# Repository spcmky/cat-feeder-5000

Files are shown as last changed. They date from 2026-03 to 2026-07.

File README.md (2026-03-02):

# Cat Feeder 5000

An automated multi-cat feeder system with RFID-gated bowl access, camera-based cat identification, scheduled feeding, and remote web control. Built on Raspberry Pi + Arduino with fully 3D-printed enclosures.

## Project Overview

- **Units**: 2 identical feeders
- **Platform**: Raspberry Pi (main brain) + Arduino Nano (motor/servo/sensor control)
- **Access Control**: RFID collar tags + camera visual verification (dual-layer)
- **Features**: Scheduled feeding, portion control, remote web control, per-cat access gating
- **Fabrication**: All structural parts 3D-printed on LulzBot Taz / Pro
- **BOM**: ~$170/feeder

## Repository Structure

```
cat-feeder-5000/
├── docs/                        # Planning documents and specs
│   ├── master-plan.md           # Full project master plan
│   └── master-plan.docx         # Word version
├── hardware/
│   ├── bom/                     # Bill of materials (CSV + spreadsheet)
│   ├── wiring/                  # Wiring diagrams and pin maps
│   └── schematics/              # Circuit schematics
├── firmware/
│   └── cat-feeder-arduino/      # Arduino sketch
├── software/
│   ├── api/                     # Flask/FastAPI backend (Pi)
│   ├── camera/                  # Camera + cat ID module
│   ├── rfid/                    # RFID access control
│   └── web/                     # Web UI
├── 3d-models/
│   ├── stl/                     # Print-ready STL files
│   ├── cad/                     # Source CAD files
│   └── print-settings/          # LulzBot slicer profiles
└── assets/                      # Images, diagrams, visuals
```

## Quick Links

- [Master Plan](docs/master-plan.md)
- [Bill of Materials](hardware/bom/)
- [Wiring Diagrams](hardware/wiring/)
- [Arduino Firmware](firmware/cat-feeder-arduino/)
- [3D Print Files](3d-models/)

## Status

🟡 **Planning Phase** — master plan complete, fabrication and coding next.

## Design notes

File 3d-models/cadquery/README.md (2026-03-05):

# CadQuery Parts — STEP/STL Export

CadQuery (Python + OpenCascade) port of the OpenSCAD parts. **Design work
happens in OpenSCAD** (`../cad/`). This directory exists for two things:

1. **STEP + STL export** — machine shops, slicers, and CAD tools that don't
   read `.scad` files. Run `export_all.py` to batch-export everything.
2. **Geometry that OpenSCAD can't do well** — the auger screw uses a true
   parametric helix (`Wire.makeHelix` + `sweep`), and the antenna arch uses
   a swept elliptical profile along a 3-point arc. Both are approximations
   in OpenSCAD.

## Quick start

```bash
source .venv/bin/activate
python export_all.py                # → exports/ directory with STEP + STL
python export_all.py --outdir /tmp  # custom output path
python parts/p05_auger_screw.py     # build + export a single part
```

## Keeping in sync

If you change dimensions in `params.scad`, update `params.py` to match.
The CadQuery parts read from `params.py` only.

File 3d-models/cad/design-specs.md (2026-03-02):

# Cat Feeder 5000 — CAD Design Specifications
All dimensions in **millimeters**. Design in Fusion 360 or FreeCAD.
Coordinate system: X = width (left-right), Y = depth (front-back), Z = height (up-down).

---

## Overall Unit Envelope

| Dimension | Value | Notes |
|---|---|---|
| Width (X) | 160 mm | |
| Depth (Y) | 220 mm | Including bowl overhang |
| Height (Z) | 320 mm | Including hopper lid |
| Bowl approach clearance | ≥ 200 mm wide × 150 mm tall | Open front zone for cat access |

---

## Part 1 — Main Body / Base

**Function**: Structural core that all other parts mount into.

| Feature | Dimension |
|---|---|
| Outer width | 160 mm |
| Outer depth | 200 mm |
| Outer height | 200 mm |
| Wall thickness | 3 mm |
| Floor thickness | 4 mm |
| Front opening (bowl zone) | 120 mm wide × 100 mm tall |
| Electronics bay (rear lower) | 80 mm × 60 mm × 50 mm |
| Auger tube hole (center) | 40 mm dia pass-through |
| M3 heat-set insert bosses | Ø5.5 mm × 6 mm deep, ×12 locations |
| Rear cable pass-through | 15 mm dia, lower rear wall |
| Bottom feet pockets | 4× Ø10 mm × 3 mm deep, 10 mm from corners |

**Notes**: Front face has large opening for bowl approach. Electronics bay accessible from removable bottom cover. All internal corners at R2mm to reduce stress.

---

## Part 2 — Food Hopper

**Function**: Food reservoir. Sits on top of main body, funnels food into auger tube.

| Feature | Dimension |
|---|---|
| Top opening (square) | 130 mm × 130 mm |
| Bottom outlet (round) | Ø38 mm (matches auger tube OD) |
| Height | 130 mm |
| Wall thickness | 2.5 mm |
| Funnel angle | 50° from vertical (exceeds 45° min) |
| Capacity (approx) | ~500 mL / ~400 g dry kibble |
| Lip for lid | 3 mm ledge, 2 mm tall, around perimeter |
| Mount tabs | 4× M3 inserts on bottom flange |

**Notes**: No sharp interior corners at funnel transition — use R5mm fillet to prevent kibble bridging.

---

## Part 3 — Hopper Lid

**Function**: Snap/screw-on cover to keep food fresh and prevent pests.

| Feature | Dimension |
|---|---|
| Outer footprint | 136 mm × 136 mm |
| Height | 20 mm |
| Wall thickness | 2 mm |
| Inner lip (snap fit) | 2 mm wide × 3 mm tall, 0.4 mm interference fit |
| Filling port option | Optional 40 mm dia flip-door in center |

**Notes**: Add 4× small vent slots (1 mm × 10 mm) under lip to prevent vacuum seal. Center filling port is optional for top-up without full lid removal.

---

## Part 4 — Auger Tube

**Function**: Channel that auger screw rotates inside to move food from hopper to bowl drop point.

| Feature | Dimension |
|---|---|
| Inner diameter | 32 mm |
| Outer diameter | 38 mm |
| Length | 120 mm |
| Wall thickness | 3 mm |
| Angle from vertical | 30° (food flows toward front/bowl) |
| Top flange (hopper join) | Ø50 mm × 5 mm, M3 holes ×3 |
| Bottom exit port | Ø28 mm, angled 90° to tube axis |

**Notes**: Inner bore must be smooth — 0.15mm layer height, 3 perimeters, food-safe lubricant. Slight taper (0.5°) at bottom helps food exit cleanly.

---

## Part 5 — Auger Screw

**Function**: Rotates inside auger tube to move kibble. Motor-driven.

| Feature | Dimension |
|---|---|
| Outer diameter | 30 mm (1 mm clearance to tube ID) |
| Pitch (thread spacing) | 20 mm |
| Thread depth | 12 mm |
| Length | 115 mm |
| Motor shaft coupler bore | Ø5 mm (N20) or Ø5 mm flat (stepper) |
| Coupler length | 15 mm |

**Notes**: Print vertically for best thread layer adhesion. Each full rotation = ~8–12g kibble (calibrate `STEPS_PER_GRAM` in firmware after printing). Add M3 set screw hole through coupler section for shaft grip.

---

## Part 6 — Motor Mount

**Function**: Mounts the auger drive motor to the main body, aligned with auger tube.

| Feature | Dimension |
|---|---|
| Overall size | 60 mm × 50 mm × 30 mm |
| Motor pocket (N20) | 12 mm × 10 mm × 25 mm deep |
| Motor pocket (stepper) | 28 mm sq × 20 mm deep |
| Shaft center offset | Matches auger tube center axis |
| Mount holes | 4× M3, matches main body bosses |

**Notes**: Design for either N20 or NEMA14 stepper (separate variants or universal with insert). Motor pocket should have 0.2 mm clearance on all sides.

---

## Part 7 — Electronics Tray

**Function**: Snap-in tray holding Pi, Arduino Nano, wiring, and power components.

| Feature | Dimension |
|---|---|
| Outer size | 78 mm × 58 mm × 20 mm |
| Pi Zero 2 W pocket | 65 mm × 30 mm × 6 mm deep |
| Arduino Nano pocket | 45 mm × 18 mm × 8 mm deep |
| Wire channel width | 8 mm |
| Snap clips | 2× 2 mm wide × 4 mm tall, 0.5 mm interference |
| Standoff height (Pi) | 3 mm (M2.5 or snap-peg style) |

**Notes**: Include cable tie slots (3 mm × 1.5 mm) every 30 mm along perimeter. Tray slides into main body from rear. Ventilation holes (Ø3 mm, 6× min) above Pi.

---

## Part 8 — Electronics Cover

**Function**: Covers electronics bay. Ventilated, removable.

| Feature | Dimension |
|---|---|
| Outer size | 84 mm × 64 mm × 5 mm |
| Vent slots | 20× slotted 2 mm × 15 mm, 3 mm spacing |
| Retention clip | 1× snap clip center, or 2× M3 screws |

---

## Part 9 — Bowl (Open-Front Design)

**Function**: Food bowl. Whisker-friendly open-front design.

| Feature | Dimension |
|---|---|
| Internal floor width | 100 mm |
| Internal floor depth | 90 mm (front-to-back) |
| Side wall height | 25 mm |
| Back wall height | 30 mm |
| Front wall | **NONE** — fully open face |
| Floor thickness | 3 mm |
| Side wall thickness | 2.5 mm |
| Floor front overhang past opening | 15 mm |
| Mounting tabs (rear) | 2× M3 insert, 10 mm from sides |
| Corner radius (internal) | R10 mm — easy cleaning |
| Drain holes (optional) | 4× Ø3 mm in floor corners |

**Notes**: The open front means no wall on the cat-facing side. Side walls taper from 25 mm at front to 30 mm at back to loosely guide food. Floor extends 15 mm past the gate opening plane so food doesn't fall out when gate opens. All interior surfaces smooth (0.15 mm layer height).

---

## Part 10 — Bowl Mounting Bracket

**Function**: Attaches bowl to main body front opening at correct height.

| Feature | Dimension |
|---|---|
| Overall size | 110 mm × 30 mm × 20 mm |
| Bowl attachment | 2× M3 holes, 90 mm apart |
| Body attachment | 4× M3 holes, countersunk |
| Bowl height from floor | Sets bowl floor at 40 mm above base |
| Tilt angle | 2° downward-front (prevents food sliding back) |

---

## Part 11 — Camera Mount / Arm

**Function**: Positions Pi Camera above and behind the bowl opening for top-down cat face view.

| Feature | Dimension |
|---|---|
| Arm length | 80 mm |
| Camera face angle | 45° downward from horizontal |
| Camera pocket | 25 mm × 25 mm × 5 mm, M2 mounts × 4 |
| Body attachment (swivel base) | M3 × 2, 15 mm apart |
| Horizontal swivel range | ±20° (slot + clamp bolt) |

**Notes**: Print with supports under the angled camera head. Camera should face down-forward to capture cat's face from ~150–200 mm distance as cat eats.

---

## Part 12 — Camera Cover / Bezel

**Function**: Cosmetic trim ring around camera lens. Protects from food dust.

| Feature | Dimension |
|---|---|
| Lens opening | Ø10 mm (Pi Camera lens is ~7.5 mm dia) |
| Outer footprint | 30 mm × 30 mm |
| Depth | 8 mm |
| Snap clips | 4× small 1 mm clips to camera mount |

---

## Part 13 — Bowl Gate / Flap (Swing-Up)

**Function**: Blocks bowl opening when closed. Swings up into feeder body when open. Servo-actuated.

| Feature | Dimension |
|---|---|
| Flap width | 118 mm (2 mm clearance each side in 120 mm opening) |
| Flap height | 90 mm (covers full bowl approach opening) |
| Thickness | 3 mm |
| Hinge rod holes (top edge) | 2× Ø3.2 mm, 20 mm from each end |
| Servo linkage hole (top center) | Ø3 mm, 10 mm from top edge |
| Bottom edge profile | R5 mm radius — no sharp edge facing cat |
| Closed position overlap | 5 mm overlap with bowl bracket each side |

**Notes**: When open (servo pulls top rearward and up), flap pivots 95–100° and rests against internal stop inside feeder body. Cat's head position during eating is ~80 mm below the hinge line — no contact possible. Print flat (face down). No texture on cat-facing side.

---

## Part 14 — Gate Top Hinge Mount

**Function**: Holds the gate flap hinge rod. Fixed to top of bowl opening frame.

| Feature | Dimension |
|---|---|
| Width | 120 mm (spans full opening) |
| Height | 20 mm |
| Depth | 15 mm |
| Hinge rod bore | 2× Ø3.2 mm, press-fit M3 shaft or use Ø3mm rod |
| Rod center height from top | 8 mm |
| Body attachment holes | 4× M3, evenly spaced |

**Notes**: Rod sits just inside the feeder body plane so gate can swing inward (upward) cleanly.

---

## Part 15 — Antenna Arch Housing

**Function**: Overhead arch that cradles the flat RFID antenna coil above the bowl approach zone.

| Feature | Dimension |
|---|---|
| Arch inner span (X) | 160 mm (full feeder width) |
| Arch inner height (Z above bowl rim) | 70 mm at peak |
| Arch depth (Y, front-to-back) | 40 mm |
| Coil channel width | 16 mm |
| Coil channel depth | 5 mm (recessed, no top perimeters over channel) |
| Coil center height above bowl floor | ~90–110 mm (adjust: want 50–80 mm above cat shoulder level) |
| Wall thickness | 2.5 mm |
| Body mount tabs | 2× M3 each side, into main body top |
| Coil channel position | Centered horizontally, centered front-to-back in arch |

**Notes**: Arch must not restrict the cat's head/neck access to the bowl. Profile: semi-elliptical arch, widest at base. Internal coil channel is open-top (no perimeter bridging over it) — coil wire is seated and fixed with food-safe epoxy. Route antenna cable through a 5 mm dia channel in the arch wall to the electronics bay.

---

## Part 16 — Gate Servo Bracket

**Function**: Mounts SG90 servo inside feeder body, connects via linkage arm to gate flap top.

| Feature | Dimension |
|---|---|
| Servo pocket | 23 mm × 12.5 mm × 30 mm deep (SG90 body) |
| Servo ear mounting holes | M2 × 2, 28 mm apart (SG90 spec) |
| Body attachment | M3 × 2 |
| Linkage arm pivot hole | Ø2 mm, 15 mm from servo shaft center |
| Position in body | Above gate hinge, ~20 mm from top wall |

**Notes**: Orient servo so horn rotates in vertical plane parallel to gate travel. With horn at 0° gate is closed; at ~95° gate is fully open (flap resting on bumper).

---

## Part 17 — TPU Gate Bumper

**Function**: Soft end-stop for gate flap in fully-open position. Absorbs servo overrun.

| Feature | Dimension |
|---|---|
| Overall size | 30 mm × 15 mm × 8 mm |
| Shore hardness | TPU 95A preferred |
| Mounting | Press-fit or M2 screw into feeder body rear wall |
| Contact face | Full 30 mm × 8 mm surface (spread impact) |
| Position | Where gate flap top edge rests when fully open |

---

## Part 18 — Feet / Non-Slip Pads

**Function**: Press-fit rubber feet, one at each corner of base. Prevents sliding.

| Feature | Dimension |
|---|---|
| Body (press-fit stud) | Ø9.8 mm dia × 6 mm tall (0.2 mm interference with Ø10 mm pocket) |
| Pad base | Ø16 mm × 4 mm |
| Material | TPU 95A |
| Quantity | 4 per unit |

---

## General Design Notes

- All M3 heat-set insert bores: **Ø4.7 mm** (M3 insert OD = 4.5 mm, +0.2 mm for print tolerance)
- All M3 clearance holes (screws pass through): **Ø3.4 mm**
- All M3 captive/tapped holes: **Ø2.5 mm** (tap M3 after printing, or use insert)
- Standard print tolerance: **±0.2 mm** — design snap fits with 0.3–0.5 mm interference
- PETG shrinkage: **~0.3–0.5%** — negligible at these scales, no compensation needed for LulzBot
- All food-contact surfaces: smooth finish (0.15 mm layer height), no sharp interior corners < R3 mm

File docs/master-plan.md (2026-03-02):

# Cat Feeder 5000 — Master Plan
**Project**: Automated Multi-Cat Feeder System
**Units**: 2 identical feeders
**Date**: 2026-03-02
**Version**: 1.2 (implanted microchip RFID + swing-up gate)

---

## Table of Contents

1. [Project Overview](#1-project-overview)
2. [System Architecture](#2-system-architecture)
3. [Bill of Materials](#3-bill-of-materials)
4. [3D-Printed Parts](#4-3d-printed-parts)
5. [Wiring & Electronics](#5-wiring--electronics)
6. [Arduino Firmware](#6-arduino-firmware)
7. [Raspberry Pi Software](#7-raspberry-pi-software)
8. [Web Interface & API](#8-web-interface--api)
9. [Design Rationale](#9-design-rationale)
10. [Risk Mitigation](#10-risk-mitigation)
11. [Project Phases & Deliverables](#11-project-phases--deliverables)

---

## 1. Project Overview

### Goal
Build two identical automated cat feeders that:
- Dispense precise food portions on a schedule
- Enforce per-cat access by reading the cat's **implanted microchip** (no collar required)
- Use a camera to visually verify which cat is present (cross-check)
- Allow full remote monitoring and control via a web app
- Are housed in professional-looking, fully 3D-printed enclosures

### Key Design Decisions
- **Open-front bowl**: Bowl has no walls at the cat's face side — low 25mm side walls, forward-extending floor. Whisker-friendly, comfortable eating position.
- **Implanted chip RFID**: Uses each cat's existing ISO 11784/11785 FDX-B microchip (134.2 kHz, implanted between the shoulders). No collar or tag required. Reader uses an EM4095 analog front end with a custom flat coil antenna mounted overhead.
- **Overhead antenna arch**: The antenna coil is positioned in a horizontal arch above and just behind the bowl opening, so the chip passes directly under it as the cat lowers its head to eat. The antenna never contacts the cat.
- **Swing-up gate**: The bowl gate flap is hinged at the top and swings up into the feeder body when open. The cat's head and back are never in the path of the gate — it cannot hit them.
- **Dual-layer cat ID**: RFID handles physical enforcement (gate open/close); camera handles visual verification and smart alerts. Cross-verification catches edge cases.
- **Two-board design**: Pi handles compute-heavy tasks (camera, web server, RFID logic). Arduino handles real-time 5V peripherals (motors, servos, sensors).

---

## 2. System Architecture

### Hardware Architecture

```
┌─────────────────────────────────────────────────────┐
│              Raspberry Pi (per feeder)               │
│  - Web server (Flask/FastAPI)                        │
│  - Camera + cat ID (OpenCV)                          │
│  - RFID access logic                                 │
│  - Schedule manager                                  │
│  - Database (SQLite)                                 │
│  - Serial comms to Arduino                           │
└──────────────────────┬──────────────────────────────┘
                       │ USB Serial (115200 baud)
┌──────────────────────▼──────────────────────────────┐
│              Arduino Nano (per feeder)               │
│  - Auger/dispense motor (stepper or DC)              │
│  - Bowl gate servo (SG90, pin D8)                    │
│  - EM4095 RFID AFE (SPI, pins D10-D13) + coil antenna│
│  - Buzzer (pin A2)                                   │
│  - Weight/load sensor (optional)                     │
│  - Status LED                                        │
└──────────────────────────────────────────────────────┘
```

### Network Architecture

```
[Cat Feeder Unit 1] ──┐
                       ├── Local WiFi ── [Router] ── [Internet]
[Cat Feeder Unit 2] ──┘                     │
                                            │
                                    [Web App / Mobile]
                                    (remote monitoring)
```

### Serial Protocol (Pi ↔ Arduino)

| Direction | Command | Description |
|---|---|---|
| Pi → Arduino | `FEED:<grams>` | Dispense specified portion |
| Pi → Arduino | `GATE:OPEN` | Open bowl gate |
| Pi → Arduino | `GATE:CLOSE` | Close bowl gate |
| Arduino → Pi | `EVENT:RFID:<uid>` | RFID tag detected (UID string) |
| Arduino → Pi | `EVENT:WEIGHT:<grams>` | Current bowl weight |
| Arduino → Pi | `STATUS:READY` | Arduino boot complete |

---

## 3. Bill of Materials

**Estimated cost: ~$170 per feeder** (×2 = ~$340 total)

### Core Electronics

| Qty | Component | Est. Cost | Notes |
|-----|---|---|---|
| 1 | Raspberry Pi Zero 2 W | $15 | Or Pi 4 for more headroom |
| 1 | Arduino Nano | $5 | Clone acceptable |
| 1 | EM4095 RFID analog front end (AFE) | $3 | 125 kHz AFE, tune LC tank to 134.2 kHz for FDX-B; SPI; 5V native — no level shifter needed. Alt: TMS3705 (TI, dedicated 134.2 kHz animal ID IC, harder to source) |
| 1 | Antenna coil (custom wound or pre-made) | $3 | Flat spiral coil, ~10–15cm diameter, tuned to 134.2 kHz with capacitor. Mounted overhead in arch housing above cat's shoulders |
| 1 | Tuning capacitor for antenna | $1 | LC tank cap, value calculated for 134.2 kHz resonance with chosen coil |
| 1 | Pi Camera Module 3 (or V2) | $25 | Wide angle preferred |
| 1 | SG90 micro servo (gate) | $3 | Swing-up gate actuation |
| 1 | N20 gear motor or NEMA 14 stepper | $8 | Auger drive |
| 1 | Motor driver (L298N or A4988) | $3 | |
| 1 | Active buzzer 5V | $1 | Feeding alert |
| 1 | 5V 3A power supply (USB-C) | $10 | Powers Pi + Arduino |
| 1 | Micro SD card 32GB | $8 | Pi OS + data |

### Mechanical & Hardware

| Qty | Component | Est. Cost | Notes |
|-----|---|---|---|
| 1 | Food-grade PETG filament (1kg) | $25 | Main body, hopper, bowl |
| 1 | TPU filament (200g) | $8 | Gate bumper, feet |
| 1 | M3 heat-set inserts (50 pack) | $6 | Assembly fasteners |
| 1 | M3 screws assorted (100 pack) | $5 | |
| 1 | Silicone food bowl liner (optional) | $5 | Hygiene, replaceable |
| — | Misc: wire, connectors, JST | $10 | |

**Total per feeder: ~$140–170 depending on sourcing**

---

## 4. 3D-Printed Parts

All parts printed on LulzBot Taz or Pro. Primary material: PETG (food-safe, durable). Gate bumper: TPU (flexible, quiet).

### Complete Parts List (18 parts)

| # | Part Name | Material | Layer Height | Infill | Supports | Notes |
|---|---|---|---|---|---|---|
| 1 | Main body / base | PETG | 0.25mm | 40% | No | Structural core, fits all internals |
| 2 | Food hopper | PETG | 0.25mm | 25% | No | 1–2 cup capacity, funnel angle ≥45° |
| 3 | Hopper lid | PETG | 0.2mm | 20% | No | Snap or screw-on, keeps food fresh |
| 4 | Auger tube | PETG | 0.2mm | 30% | No | Food-grade, smooth inner bore |
| 5 | Auger screw | PETG | 0.15mm | 60% | Yes | Precision thread, calibrate for portion accuracy |
| 6 | Motor mount | PETG | 0.25mm | 40% | No | Mounts auger drive motor |
| 7 | Electronics tray | PETG | 0.25mm | 30% | No | Holds Pi, Arduino, wiring; snap-in |
| 8 | Electronics cover | PETG | 0.2mm | 20% | No | Ventilation slots, removable |
| 9 | Bowl — open-front design | PETG | 0.15mm | 30% | No | No face-side wall; low 25mm side walls; floor extends forward; whisker-friendly |
| 10 | Bowl mounting bracket | PETG | 0.25mm | 40% | No | Secures bowl to main body |
| 11 | Camera mount / arm | PETG | 0.2mm | 35% | Yes | Angled for top-down cat face view |
| 12 | Camera cover / bezel | PETG | 0.2mm | 20% | No | Cosmetic, protects lens |
| 13 | **Bowl gate / flap — swing-up** *(RFID)* | PETG | 0.15mm | 40% | No | Hinged at top of bowl opening; swings up into feeder body when open. Cat's head and back are never in the path of travel. Servo-actuated |
| 14 | **Gate top hinge mount** *(RFID)* | PETG | 0.2mm | 40% | No | Mounts gate flap pivot at top of bowl opening; keeps gate travel path above the cat |
| 15 | **Antenna arch housing** *(RFID)* | PETG | 0.2mm | 25% | No | Overhead arch that positions the flat coil antenna horizontally above the approach zone, ~5–8cm above where the cat's shoulders sit while eating. Coil slots into a recessed channel inside the arch. Sized so gate flap retracts into the feeder body above it |
| 16 | **Gate servo bracket** *(RFID)* | PETG | 0.2mm | 40% | No | Mounts SG90 servo inside feeder body; linkage arm connects to top of gate flap |
| 17 | **TPU gate bumper** *(RFID)* | TPU | 0.2mm | 30% | No | Soft stop at top of gate travel (fully open position); prevents servo overrun and rattle |
| 18 | Feet / non-slip pads | TPU | 0.3mm | 15% | No | 4 per unit, press-fit into base |

### LulzBot Print Notes

- **PETG settings (Taz/Pro)**: 240°C nozzle / 70–80°C bed. 0.5mm nozzle recommended for structural parts. Dry filament before printing (PETG is hygroscopic).
- **TPU settings**: 220°C nozzle / 45°C bed. Disable retraction or minimize. Print slow (25–30mm/s).
- **Food contact parts** (auger, bowl): Use food-safe PETG, 3+ perimeters, 40%+ infill, food-safe lubricant only on auger.
- **Orientation**: Print auger screw vertically for thread integrity. Print gate flap flat (face down). Print antenna arch upright — thin walls need orientation parallel to print direction for layer bonding strength.
- **Antenna coil channel**: Leave a 2–3mm recessed groove inside the arch for the coil wire. Print without top-surface perimeters over the channel so coil can be seated and epoxied in place.

---

## 5. Wiring & Electronics

### Arduino Pin Map

| Pin | Function | Component |
|-----|---|---|
| D2 | Stepper STEP or motor PWM | Motor driver |
| D3 | Stepper DIR or motor IN2 | Motor driver |
| D4 | Motor driver enable | L298N/A4988 EN |
| D5 | RFID modulation (MOD) | EM4095 |
| D6 | RFID RF off (RF_OFF) | EM4095 |
| D8 | Gate servo PWM | SG90 servo (swing-up gate) |
| D9 | Status LED | LED + resistor |
| **D10** | **RFID chip select (CS)** | **EM4095** |
| **D11** | **SPI MOSI** | **EM4095** |
| **D12** | **SPI MISO / DEMOD_OUT** | **EM4095** |
| **D13** | **SPI SCK** | **EM4095** |
| A2 | Buzzer | Active buzzer |
| A4 | I2C SDA (optional) | Load cell amp |
| A5 | I2C SCL (optional) | Load cell amp |

> **NOTE**: EM4095 is a **5V device** — no level converter needed. Power directly from Arduino 5V. The antenna coil connects to the COIL1/COIL2 pins on the EM4095 via the LC tank circuit (coil + tuning cap resonant at 134.2 kHz).

### Antenna Coil Design

The read range and reliability of the implanted chip detection depends entirely on the antenna coil. Key parameters:

| Parameter | Target value |
|---|---|
| Coil diameter | 10–15 cm flat spiral |
| Number of turns | 10–20 (tune for resonance) |
| Resonant frequency | 134.2 kHz (FDX-B) |
| Target read range | 5–8 cm (sufficient for chip ~2–4 cm below skin) |
| Coil position | Horizontal, centered in arch housing, ~5–8 cm above cat shoulder level |
| Coil orientation | Flat/horizontal — maximizes flux through chip (chip axis is vertical when cat's back is level) |

**LC tank resonance formula**: `f = 1 / (2π√(LC))` — choose L (coil inductance), solve for C. Wind coil, measure inductance with LCR meter or Arduino LC meter, then calculate exact cap value.

### Power Architecture

```
USB-C 5V 3A PSU
    ├── Raspberry Pi (5V via USB-C)
    └── Arduino Nano (5V via USB or Vin)
            ├── SG90 servo (5V, ~250mA peak)
            ├── Motor driver (5V logic, motor on separate 5-12V if needed)
            ├── Buzzer (5V)
            └── EM4095 + coil antenna (5V, ~50–100mA during read)
```

### RFID Wiring (EM4095 ↔ Arduino Nano)

| EM4095 Pin | Arduino Pin | Notes |
|---|---|---|
| VCC | 5V | 5V native — no level shifter |
| GND | GND | |
| COIL1 | — | To LC tank coil (one end) |
| COIL2 | — | To LC tank coil (other end) |
| DEMOD_OUT | D12 (MISO) | Demodulated data out |
| MOD | D5 | Modulation input (for write capability) |
| RF_OFF | D6 | Pull high to disable RF field |
| SHD | GND | Pull low to enable (or use D-pin for software control) |

---

## 6. Arduino Firmware

### Responsibilities
- Drive the EM4095 antenna coil to read FDX-B implanted microchip UIDs; report to Pi over serial
- Actuate swing-up gate servo (open = flap retracts into body above bowl; close = flap blocks bowl opening)
- Drive auger motor for food dispensing (on Pi command)
- Sound buzzer for feeding alerts
- Optionally read load cell for bowl weight

### Key Serial Commands

```
Pi → Arduino:
  FEED:<grams>        — dispense specified grams
  GATE:OPEN           — open bowl gate flap
  GATE:CLOSE          — close bowl gate flap
  BUZZ:<pattern>      — trigger buzzer (1=short, 2=long, 3=error)

Arduino → Pi:
  EVENT:RFID:<uid>    — RFID tag detected with UID
  EVENT:WEIGHT:<g>    — bowl weight reading
  STATUS:READY        — boot complete
  STATUS:GATE:OPEN    — gate opened confirmation
  STATUS:GATE:CLOSED  — gate closed confirmation
```

### Gate State Machine

```
[CLOSED] → RFID detected → Pi validates → GATE:OPEN → [OPEN]
[OPEN] → 30s timeout → GATE:CLOSE → [CLOSED]
[OPEN] → cat leaves (weight sensor) → GATE:CLOSE → [CLOSED]
```

### Source Files
- `firmware/cat-feeder-arduino/cat-feeder-arduino.ino` — main sketch
- Libraries: `Servo`, `AccelStepper`
- RFID decoding: custom Manchester decoder for FDX-B bit stream from EM4095 DEMOD_OUT. No off-the-shelf Arduino library covers EM4095 + FDX-B directly — implementation uses timer interrupt to sample DEMOD_OUT at 2× bit rate and decode Manchester encoding.

---

## 7. Raspberry Pi Software

### Python Modules

| Module | File | Purpose |
|---|---|---|
| Main daemon | `main.py` | Orchestrates all services |
| Schedule manager | `scheduler.py` | Feeding schedule, cron-like |
| Serial bridge | `serial_bridge.py` | Pi ↔ Arduino serial comms |
| RFID access control | `rfid_access.py` | Tag registration, access decisions |
| Gate controller | `gate_controller.py` | Gate open/close logic, timeout |
| Camera / cat ID | `camera.py` | OpenCV, cat face detection |
| Database | `db.py` | SQLite ORM layer |
| API server | `api/app.py` | Flask/FastAPI REST API |

### Database Schema (SQLite)

```sql
-- Cats
CREATE TABLE cats (
  id INTEGER PRIMARY KEY,
  name TEXT NOT NULL,
  rfid_uid TEXT,           -- RFID collar tag UID
  photo_embedding BLOB,    -- Camera ID feature vector
  daily_portion_g INTEGER DEFAULT 80,
  created_at TIMESTAMP DEFAULT CURRENT_TIMESTAMP
);

-- RFID tags
CREATE TABLE rfid_tags (
  id INTEGER PRIMARY KEY,
  uid TEXT UNIQUE NOT NULL,
  cat_id INTEGER REFERENCES cats(id),
  active BOOLEAN DEFAULT 1,
  registered_at TIMESTAMP DEFAULT CURRENT_TIMESTAMP
);

-- Feeding events
CREATE TABLE feeding_log (
  id INTEGER PRIMARY KEY,
  cat_id INTEGER REFERENCES cats(id),
  feeder_id INTEGER,
  trigger TEXT,            -- 'schedule', 'manual', 'rfid'
  portion_g INTEGER,
  dispensed_at TIMESTAMP DEFAULT CURRENT_TIMESTAMP
);

-- RFID access events
CREATE TABLE access_log (
  id INTEGER PRIMARY KEY,
  rfid_uid TEXT,
  cat_id INTEGER REFERENCES cats(id),
  feeder_id INTEGER,
  result TEXT,             -- 'granted', 'denied', 'unknown_tag'
  camera_verify TEXT,      -- 'match', 'mismatch', 'skipped'
  accessed_at TIMESTAMP DEFAULT CURRENT_TIMESTAMP
);

-- Feeding schedules
CREATE TABLE schedules (
  id INTEGER PRIMARY KEY,
  feeder_id INTEGER,
  cat_id INTEGER REFERENCES cats(id),
  time TEXT NOT NULL,      -- 'HH:MM' format
  portion_g INTEGER,
  enabled BOOLEAN DEFAULT 1
);
```

### Cat Identification Pipeline

```
1. RFID tag detected (Arduino → Pi)
2. Pi looks up tag in rfid_tags table → gets cat_id
3. Pi sends GATE:OPEN to Arduino (physical access granted)
4. Camera captures frame, runs face detection (OpenCV)
5. Compare detected cat against registered cat embeddings
6. If RFID cat ≠ camera cat → log alert, optionally close gate
7. Log event to access_log with both RFID and camera results
```

---

## 8. Web Interface & API

### REST API Endpoints

| Method | Endpoint | Description |
|---|---|---|
| GET | `/api/status` | Feeder status, last event |
| GET | `/api/cats` | List registered cats |
| POST | `/api/cats` | Register new cat |
| GET | `/api/feeding-log` | Recent feeding history |
| POST | `/api/feed` | Manual feed trigger |
| GET | `/api/schedule` | Get feeding schedule |
| PUT | `/api/schedule` | Update schedule |
| GET | `/api/rfid/tags` | List registered RFID tags |
| POST | `/api/rfid/pair` | Pair new RFID tag to cat |
| DELETE | `/api/rfid/tags/:id` | Remove RFID tag |
| POST | `/api/gate/open` | Manual gate open |
| POST | `/api/gate/close` | Manual gate close |
| GET | `/api/access-log` | RFID access event log |
| GET | `/api/camera/snapshot` | Live camera frame |

### Web UI Features
- Dashboard: live status for both feeders
- Feeding history chart (per cat, per day)
- Schedule editor (drag-and-drop time slots)
- Cat profile management (photo, name, portion size)
- RFID tag management (pair, disable, re-pair)
- Access log with camera snapshots
- Manual feed button
- Gate control (override open/close)

---

## 9. Design Rationale

### Why Pi + Arduino (not Pi alone)?
The Pi GPIO is not well-suited for real-time PWM servo/stepper control, and 5V peripherals require level shifting. The Arduino handles time-critical 5V tasks reliably, while the Pi focuses on compute: camera inference, web serving, and RFID logic. USB serial provides a clean, reliable bridge.

### Why Implanted Chip (Not Collar Tag)?
The cat's ISO 11784/11785 FDX-B microchip is already implanted between the shoulders — it's permanent, can't be removed, lost, or swapped between cats. Collar tags require the cat to always be wearing the collar, and cats are notorious for losing them. Using the implanted chip eliminates an entire class of failure modes and means no new hardware needs to be attached to the cat.

### Why EM4095 + Custom Coil (Not RC522/MFRC522)?
The MFRC522 operates at 13.56 MHz (ISO 14443 / ISO 15693) — it physically cannot read implanted pet microchips, which operate at 134.2 kHz (FDX-B). The EM4095 is a 5V-native LF analog front end designed for exactly this frequency range. A custom-wound flat coil tuned to 134.2 kHz via an LC tank gives precise control over read range and antenna geometry.

### Why Overhead Antenna Arch (Not Front-Mounted)?
The microchip is between the cat's shoulder blades. As the cat lowers its head to the bowl, the shoulders are roughly level with the bowl rim. A front-mounted antenna would require the chip to pass horizontally through the read field — awkward geometry, poor coupling. An overhead flat coil positioned above the shoulder zone reads the chip at nearly optimal angle (coil plane parallel to the cat's back, flux perpendicular to chip axis) as the cat settles into eating position.

### Why RFID + Camera (dual-layer)?
RFID alone can't catch the edge case of one cat crouching right behind another. Camera alone is compute-heavy and can fail in low light. Together they provide reliable access: RFID opens the gate physically, camera confirms visually and catches anomalies.

### Why Open-Front Bowl?
Cats have sensitive whiskers. Deep or walled bowls cause "whisker fatigue" — discomfort when whiskers touch bowl sides during eating. The open-front design with low 25mm side walls and a forward-extending floor allows cats to eat comfortably without whisker contact, while still containing food adequately.

### Why RFID Gate Instead of Camera-Gated Gate?
Camera inference adds latency (100–500ms) on a Pi Zero. An RFID reader responds in <50ms and requires no compute. Using RFID for the physical gate and camera only for cross-verification gives fast, reliable physical access control with the smart verification layer as a safety net.

### Why Swing-Up Gate?
A downward-swinging or forward-opening gate creates a collision risk as the cat approaches or backs away. A swing-up gate retracts fully into the feeder body above the bowl — it is physically impossible for it to contact the cat's head or back during normal operation. The servo travel path is internal to the unit.

### Why Full 3D-Print?
Full 3D printing means every dimension can be tuned, iterated, and upgraded without new tooling. PETG is food-safe, durable, and easy to clean. Custom prints also enable purpose-fit cable routing, snap-fit assembly, and aesthetics not possible with off-the-shelf parts.

---

## 10. Risk Mitigation

| Risk | Likelihood | Impact | Mitigation |
|---|---|---|---|
| Wrong cat eats from open feeder | Medium | High | RFID gate physically blocks access; camera cross-checks |
| Chip not read as cat approaches | Low | Medium | Antenna coil sized and positioned for optimal coupling; cat must be in position to eat before gate opens anyway; retry logic in firmware polls at ~10 Hz |
| Chip read angle poor (cat tilts/crouches oddly) | Low | Low | Flat coil with 10–15cm diameter gives generous field volume; minor angle variation (<30°) has negligible effect on FDX-B coupling |
| Gate hits cat | Very Low | Medium | Swing-up design: gate retracts into body above the bowl — physically cannot contact the cat. TPU bumper stops servo at top of travel |
| Gate servo jam | Low | Medium | 30s auto-close timeout; manual override in web UI; swing-up means gravity assists closing |
| Two cats approach simultaneously | Low | Medium | Gate only opens for one UID at a time; coil read range limited to ~8cm so second cat is too far to trigger |
| Antenna LC tank drifts off resonance (temperature) | Low | Low | PETG housing insulates coil; resonance measured at room temp; minor drift at 134.2 kHz is tolerable given FDX-B chip sensitivity |
| Pi Zero underpowered for camera + web | Medium | Low | Optimize OpenCV pipeline; or upgrade to Pi 4 Model B |
| Auger clog | Medium | Medium | Food-grade PETG smooth bore; minimum 45° hopper angle; jam-detection via stall sensing |
| Food spoilage in hopper | Low | Medium | Hopper lid keeps food fresh; programmable max daily portion limits |
| Cat ignores feeder | Low | Low | Schedule-based buzz alert; treat-dispensing mode as incentive |

---

## 11. Project Phases & Deliverables

### Phase 1 — Hardware & Prototyping (Weeks 1–3)
- [ ] Source all components (BOM)
- [ ] Wind test coil, calculate LC tank cap for 134.2 kHz, verify resonance with LCR meter
- [ ] Breadboard test: Arduino + EM4095 + test coil → successfully read cat's implanted chip
- [ ] Verify read range with coil at different heights above cat's shoulders
- [ ] Breadboard test: swing-up gate servo travel and clearance geometry
- [ ] Validate serial protocol between Pi and Arduino
- [ ] Test camera with basic OpenCV cat detection

### Phase 2 — 3D Design & Printing (Weeks 2–5, parallel)
- [ ] CAD all 18 parts in Fusion 360 / FreeCAD
- [ ] Print and test-fit main body, hopper, auger
- [ ] Print and test bowl (open-front design) + gate mechanism
- [ ] Print RFID housing, gate servo bracket, TPU bumper
- [ ] Full assembly dry-run, iterate as needed

### Phase 3 — Firmware (Weeks 3–4)
- [ ] Arduino sketch: RFID reading, serial commands
- [ ] Gate state machine (open/close/timeout)
- [ ] Auger/motor control, portion calibration
- [ ] Buzzer patterns

### Phase 4 — Pi Software (Weeks 4–6)
- [ ] Serial bridge + scheduler
- [ ] SQLite schema + db.py
- [ ] rfid_access.py + gate_controller.py
- [ ] Camera pipeline + cat ID embeddings
- [ ] Flask API (all endpoints)
- [ ] Web UI

### Phase 5 — Integration & Testing (Weeks 6–8)
- [ ] Full system integration test (both units)
- [ ] RFID pairing for all cats
- [ ] Schedule setup + feeding calibration
- [ ] Edge case testing (simultaneous approach, lost tag, jams)
- [ ] Final assembly and cable management

### Final Deliverables
- [ ] 2× fully assembled Cat Feeder 5000 units
- [ ] Arduino firmware (`firmware/`)
- [ ] Pi Python software (`software/`)
- [ ] Web UI (`software/web/`)
- [ ] All 3D-print files (`3d-models/`)
- [ ] Wiring schematics (`hardware/wiring/`)
- [ ] Bill of materials (`hardware/bom/`)
- [ ] This master plan document (`docs/`)

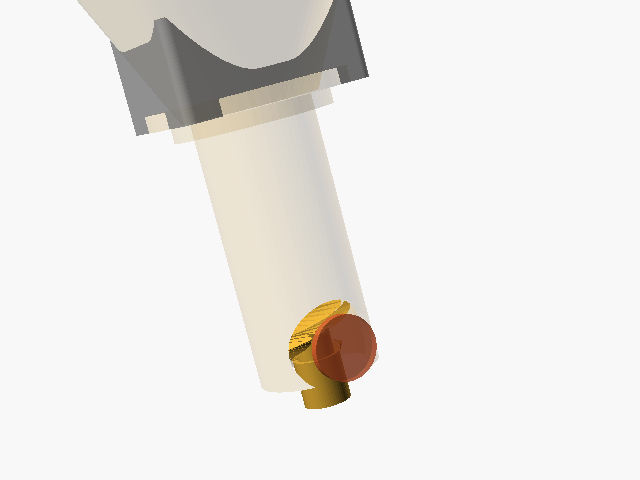
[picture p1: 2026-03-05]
3d-models/renders/anim_frames/frame_04.png

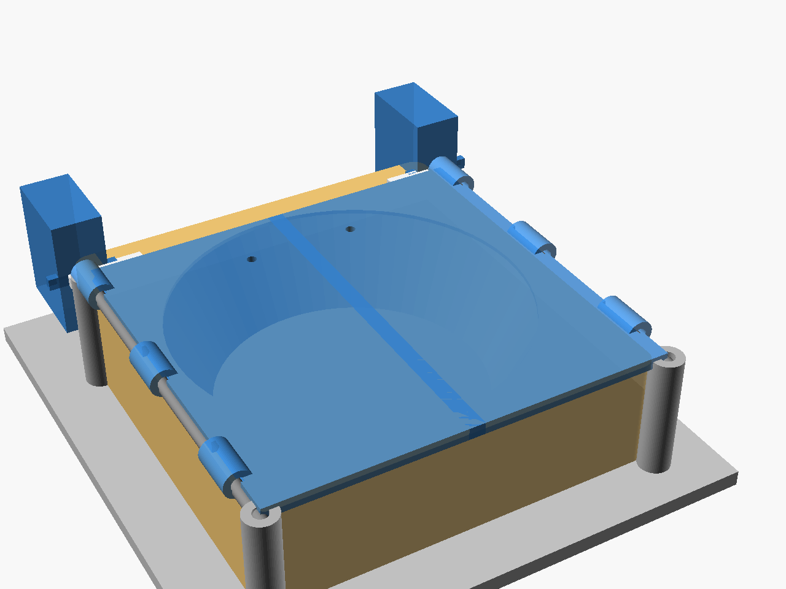
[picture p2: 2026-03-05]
3d-models/renders/detail_flaps_corner.png

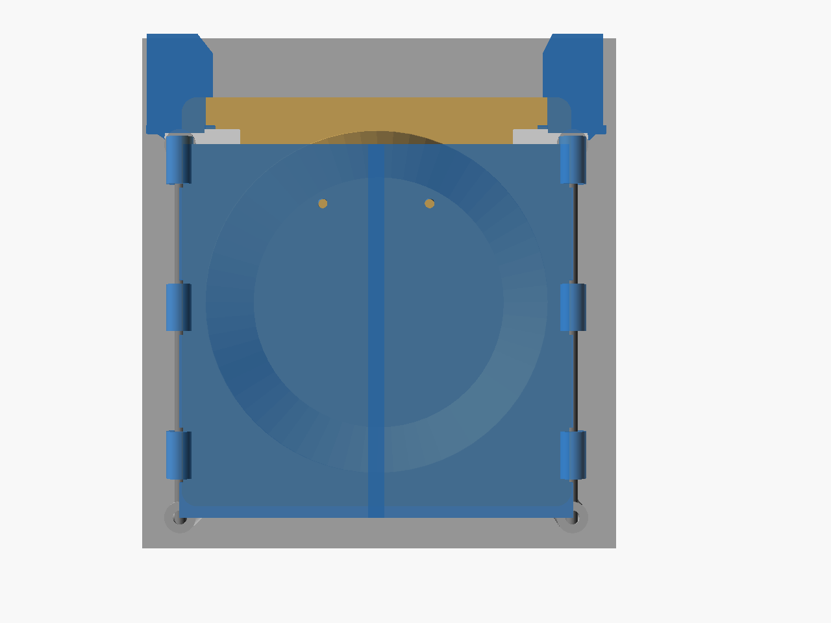
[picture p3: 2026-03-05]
3d-models/renders/detail_flaps_top.png

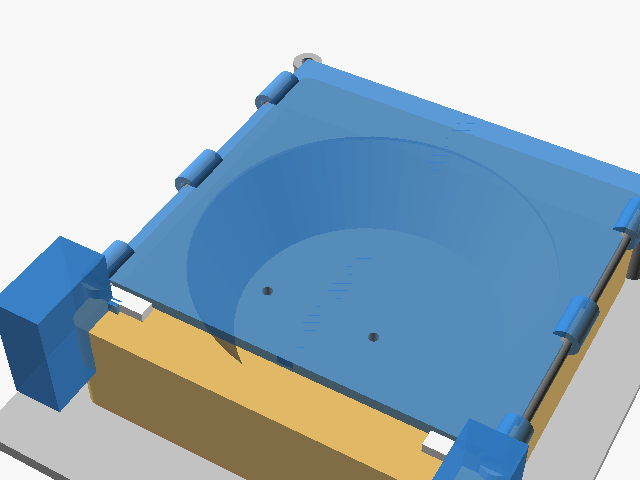
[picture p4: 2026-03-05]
3d-models/renders/detail_flaps_servo_animation.gif

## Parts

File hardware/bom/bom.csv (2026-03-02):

qty | component | unit_cost_usd | total_cost_usd | supplier_notes | category
1 | Raspberry Pi Zero 2 W | 15.00 | 15.00 | Adafruit / PiShop | compute
1 | Arduino Nano (clone OK) | 5.00 | 5.00 | Amazon / AliExpress | compute
1 | EM4095 RFID analog front end (SOIC-16) | 3.00 | 3.00 | Mouser / DigiKey — EM4095HMSO/V; alt: TMS3705 (TI) for dedicated 134.2 kHz | rfid
1 | Magnet wire 28 AWG, 10m | 2.00 | 2.00 | For winding 134.2 kHz flat antenna coil (~12cm dia | 15 turns) | rfid
1 | Tuning capacitor assortment (100pF–10nF) | 1.00 | 1.00 | For LC tank resonance at 134.2 kHz; calc value after measuring coil L | rfid
1 | Pi Camera Module V2 (or V3) | 25.00 | 25.00 | Adafruit / Amazon — wide angle preferred | camera
1 | SG90 micro servo | 3.00 | 3.00 | For swing-up gate actuation | actuation
1 | N20 gear motor 60 RPM 6V, or NEMA14 stepper | 8.00 | 8.00 | N20 for simple DC; NEMA14 for precise portion control | actuation
1 | Motor driver (A4988 or L298N module) | 3.00 | 3.00 | A4988 for stepper; L298N for DC | actuation
1 | Active buzzer 5V | 1.00 | 1.00 | Through-hole; 5V active | audio
1 | USB-C power supply 5V 3A | 10.00 | 10.00 | Powers Pi + Arduino; quality supply important | power
1 | Micro SD card 32GB | 8.00 | 8.00 | For Pi OS + SQLite database | storage
1 | Logic level converter 4-channel (optional) | 1.50 | 1.50 | Not needed for EM4095 (5V) but useful for other sensors | misc
1 | M3 heat-set inserts, 50 pack | 6.00 | 6.00 | McMaster-Carr or Amazon | mechanical
1 | M3 screws assorted 100 pack (6mm + 10mm) | 5.00 | 5.00 | Amazon | mechanical
1 | Food-grade PETG filament 1kg | 25.00 | 25.00 | eSUN or Polymaker food-safe PETG — main body / bowl | 3d_print
1 | TPU 95A filament 200g | 8.00 | 8.00 | Gate bumper + feet | 3d_print
1 | Silicone bowl liner (optional) | 5.00 | 5.00 | Replaceable food-contact surface | optional
1 | Wire assortment + JST connectors | 10.00 | 10.00 | Misc wiring harness | misc
 |  |  |  | TOTAL PER FEEDER:
 |  |  |  | ~$145–175 depending on sourcing

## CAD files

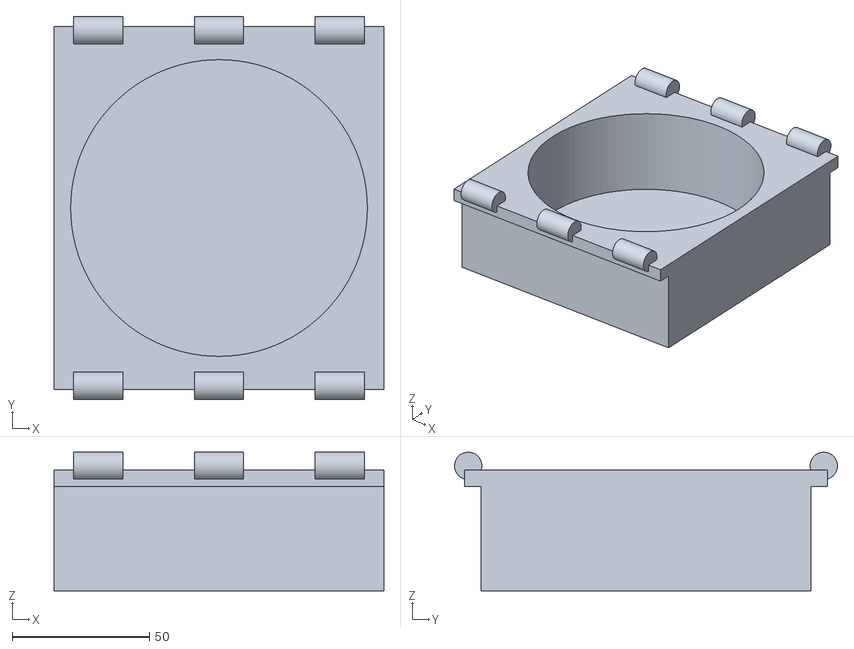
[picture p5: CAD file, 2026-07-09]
3d-models/bowl/base.stl
120.0 x 139.4 x 50.5

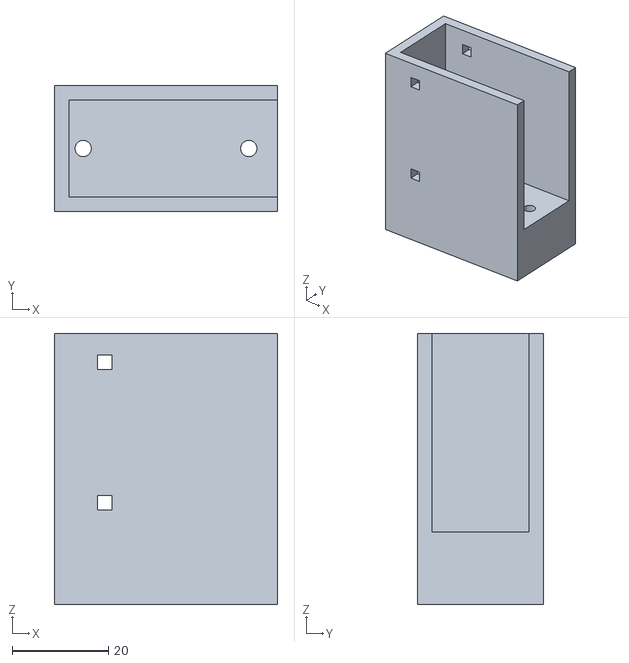
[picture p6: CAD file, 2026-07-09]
3d-models/bowl/servo_mount_v4.stl
46.4 x 26.2 x 56.3

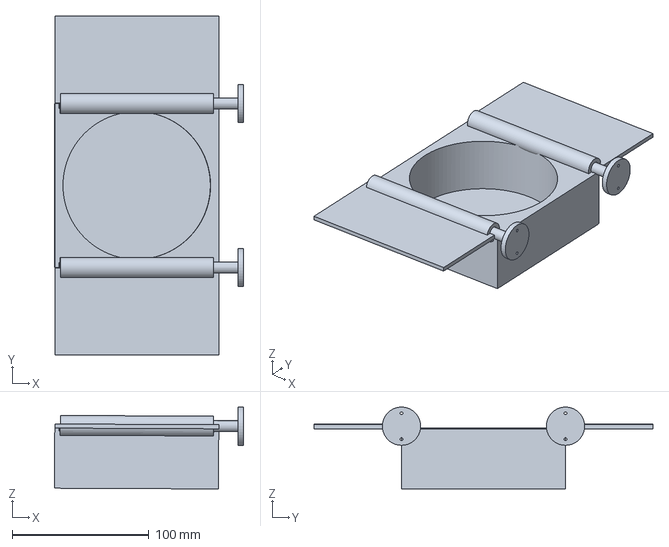
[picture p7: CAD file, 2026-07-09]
3d-models/bowl/combined_v4.3mf
138.3 x 248.0 x 59.9 mm

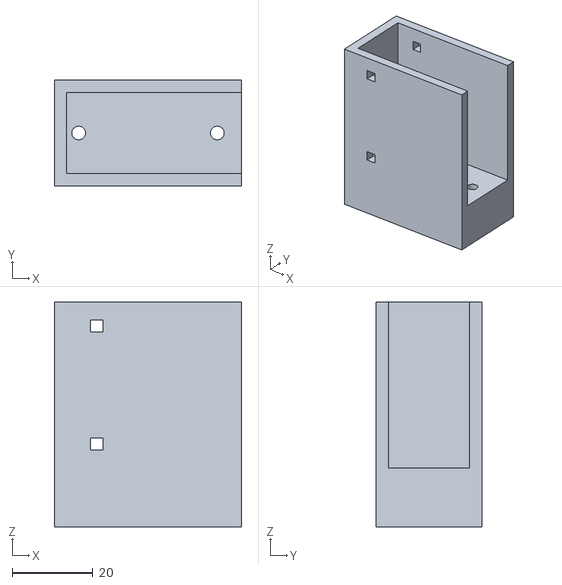
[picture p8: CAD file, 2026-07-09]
3d-models/bowl/servo_mount.stl
46.4 x 26.2 x 55.8

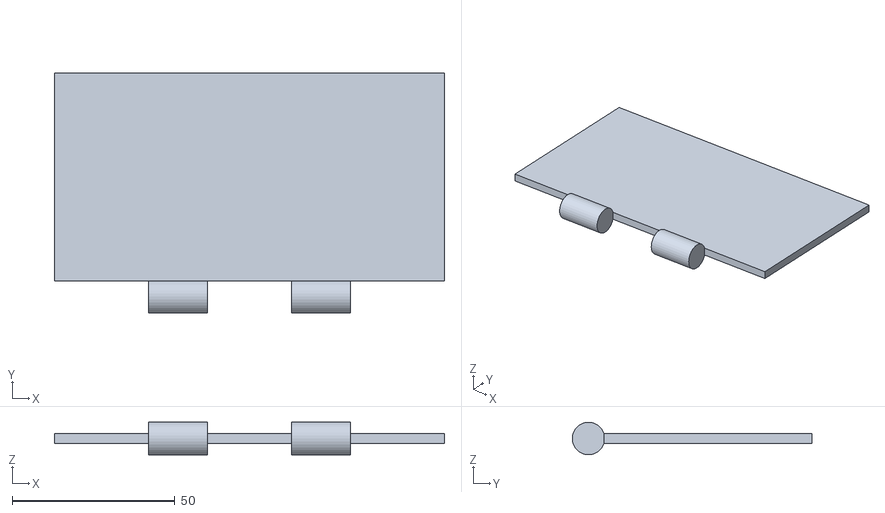
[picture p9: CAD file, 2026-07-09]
3d-models/bowl/flap.stl
120.0 x 73.7 x 10.0

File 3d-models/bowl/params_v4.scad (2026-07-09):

// ============================================================
// params_v4.scad — print-in-place hinge, single continuous barrel
// Base + both flaps print together as ONE piece, flat/open (like
// the reference box), then fold closed by hand after printing.
// No rod, no pins, no hardware, no snap-assembly step.
// ============================================================
$fn = 64;

// ---- Bowl ----
BOWL_DIA      = 108;
BOWL_DEPTH    = 40;
BOWL_RADIUS   = BOWL_DIA / 2;

// ---- Base block ----
WALL          = 6;
FLOOR_T       = 4;
BASE_SIZE     = BOWL_DIA + 2 * WALL;     // 120mm square
BASE_HEIGHT   = BOWL_DEPTH + FLOOR_T;    // 44mm

// ---- Flap ----
FLAP_LEN      = BASE_SIZE;
FLAP_OVERLAP  = 4;
FLAP_DEPTH    = BASE_SIZE / 2 + FLAP_OVERLAP;
FLAP_T        = 3;

// ---- Print-in-place barrel hinge ----
PIN_D         = 8;                  // pin diameter
SOCKET_CLEAR  = 0.5;                // total diametral clearance (tune per printer/material)
SOCKET_ID     = PIN_D + SOCKET_CLEAR;
SOCKET_SHELL  = 3;
SOCKET_OD     = SOCKET_ID + 2 * SOCKET_SHELL;
END_MARGIN    = 4;                  // inset from each end of the edge
BARREL_LEN    = FLAP_LEN - 2 * END_MARGIN;   // socket length (both hinges)

// reinforcement ridge so the thin panel/base have enough material to embed the pin
PAD_DEPTH     = 10;
FLAP_PAD_H    = PIN_D + 2;
// HINGE_Z is set so the pin/socket genuinely overlaps into both the base
// block and the flap panel (a few mm of real volumetric overlap) rather
// than sitting exactly tangent to a flat face — exact tangency between
// separate solids is a classic non-manifold CSG trap.
HINGE_EMBED   = 2;  // how far the joint dips below the base's top surface
HINGE_Z       = BASE_HEIGHT + HINGE_EMBED;

// small relief gap so the flap panel doesn't touch the base along a bare
// edge (that kind of zero-area contact causes non-manifold CSG results,
// and physically the panel doesn't need to touch — only the pin/socket
// joint should connect the two pieces).
HINGE_GAP     = 0.4;
BASE_PAD_H    = (HINGE_Z - BASE_HEIGHT) + SOCKET_OD / 2 + 2;

// ---- Servo drive extension (flap's pin extends past the base to meet the horn) ----
SERVO_EXT_LEN = 22;                 // how far the pin extends past the base edge
SERVO_HORN_OD = 24;                 // verify with calipers
SERVO_HORN_BOLT_CIRCLE = 19;        // verify with calipers
SERVO_BOSS_D  = SERVO_HORN_OD + 4;
SERVO_BOSS_T  = 4;
M3_CLEAR      = 3.4;

// ---- MG996R servo body (for the separate bracket — still a physical part) ----
SERVO_W       = 40.7;
SERVO_D       = 19.7;
SERVO_H       = 42.9;
SERVO_SHAFT_OFFSET = 30.9;

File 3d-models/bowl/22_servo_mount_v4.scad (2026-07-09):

// ============================================================
// 22_servo_mount_v2.scad — MG996R bracket, shaft aligned to rod
// The servo is rotated 90° from its usual orientation so the
// output shaft points sideways (along +X) into the rod/coupler,
// instead of the usual "shaft points up" mounting.
//
// Pocket is open on TOP (drop the servo in) and open on the
// FRONT/+X face (shaft + horn protrude toward the base). Servo
// is held with zip-tie slots rather than modeled ear-mount holes,
// since exact ear spacing varies by MG996R clone — verify yours
// with calipers; zip ties are forgiving of small errors for v1.
//
// Print orientation: as-is, flat on the bed.
// ============================================================
include <params_v4.scad>

WALL2   = 3;
TOL     = 0.5;   // pocket clearance around servo body

// after 90° remap: X-extent(depth into bracket)=SERVO_H, Y-extent=SERVO_D, Z-extent=SERVO_W
POCKET_X = SERVO_H + TOL;
POCKET_Y = SERVO_D + TOL;
POCKET_Z = SERVO_W + TOL;

// shaft sits 30.9mm up from the pocket's "bottom" (see params_v4 SERVO_SHAFT_OFFSET)
POCKET_BOTTOM_Z = HINGE_Z - SERVO_SHAFT_OFFSET;

BX = WALL2 + POCKET_X;              // back wall + pocket depth (front left open)
BY = POCKET_Y + 2 * WALL2;          // side walls both sides
BZ = POCKET_BOTTOM_Z + POCKET_Z;    // pedestal + pocket height (top left open)

module servo_pocket() {
    translate([WALL2, WALL2, POCKET_BOTTOM_Z])
        cube([POCKET_X + 5, POCKET_Y, POCKET_Z + 5]); // +5 extends through front & top (open)
}

module ziptie_slots() {
    // two slot pairs (through both side walls), one near pocket bottom, one near top
    for (z = [POCKET_BOTTOM_Z + 6, POCKET_BOTTOM_Z + POCKET_Z - 6]) {
        translate([WALL2 + 6, -1, z - 1.5])
            cube([3, BY + 2, 3]);
    }
}

module mount_holes() {
    // 2x M3 through the pedestal, for screwing bracket to a shared platform/board
    for (x = [6, BX - 6])
        translate([x, BY / 2, -0.1])
            cylinder(d = M3_CLEAR, h = POCKET_BOTTOM_Z + 0.2, $fn = 24);
}

module servo_bracket() {
    difference() {
        cube([BX, BY, BZ]);
        servo_pocket();
        ziptie_slots();
        mount_holes();
    }
}

servo_bracket();

// ---- reference: where the shaft/horn ends up in world coords (for the assembly) ----
echo("Servo shaft center (local bracket coords): X =", BX, " Y =", BY/2, " Z =", HINGE_Z);

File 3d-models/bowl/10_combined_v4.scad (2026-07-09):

// ============================================================
// 10_combined_v4.scad — ONE PIECE: base + both flaps, flat/open
// Print exactly as modeled (flat, pocket up) — hinges are already
// assembled by the print itself. Fold each flap closed by hand
// after printing (PETG flexes enough at this pin diameter; do a
// few slow open/close cycles right off the bed while it's still
// slightly warm to work the joint in).
//
// Each flap's pin extends past one end of the base to meet a
// servo horn directly — see SERVO_EXT_LEN in params_v4.scad.
// ============================================================
include <params_v4.scad>
include <hinge_v4.scad>

// ---------------- Base ----------------
module base_block() {
    difference() {
        cube([BASE_SIZE, BASE_SIZE, BASE_HEIGHT]);
        translate([BASE_SIZE / 2, BASE_SIZE / 2, FLOOR_T])
            cylinder(r = BOWL_RADIUS, h = BOWL_DEPTH + 1, $fn = 96);
    }
}

module base_socket_shell(edge) {
    if (edge == "front")
        translate([END_MARGIN, 0, HINGE_Z])
            socket_outer(BARREL_LEN);
    else
        translate([END_MARGIN, BASE_SIZE, HINGE_Z])
            socket_outer(BARREL_LEN);
}

module base_socket_bore(edge) {
    // extended slightly past both ends for a clean cut
    if (edge == "front")
        translate([END_MARGIN - 1, 0, HINGE_Z])
            socket_bore(BARREL_LEN + 2);
    else
        translate([END_MARGIN - 1, BASE_SIZE, HINGE_Z])
            socket_bore(BARREL_LEN + 2);
}

// base_block + both socket shells, unioned, THEN both bores cut through
// everything at once — this is what gives the pin real clearance even in
// the region where the socket is embedded inside the base block.
module base_assembly() {
    difference() {
        union() {
            base_block();
            base_socket_shell("front");
            base_socket_shell("back");
        }
        base_socket_bore("front");
        base_socket_bore("back");
    }
}

// ---------------- Flap (flat/open pose) ----------------
// front flap occupies Y: -FLAP_DEPTH..0 ; back flap occupies Y: BASE_SIZE..BASE_SIZE+FLAP_DEPTH
module flap_panel(edge) {
    if (edge == "front")
        translate([0, -FLAP_DEPTH, BASE_HEIGHT])
            cube([FLAP_LEN, FLAP_DEPTH - HINGE_GAP, FLAP_T]);
    else
        translate([0, BASE_SIZE + HINGE_GAP, BASE_HEIGHT])
            cube([FLAP_LEN, FLAP_DEPTH - HINGE_GAP, FLAP_T]);
}

// pin extends SERVO_EXT_LEN past the low-X end to reach the servo horn
module flap_pin(edge) {
    total_len = BARREL_LEN + SERVO_EXT_LEN;
    start_x = END_MARGIN - SERVO_EXT_LEN;
    if (edge == "front")
        translate([start_x, 0, HINGE_Z])
            pin_barrel(total_len);
    else
        translate([start_x, BASE_SIZE, HINGE_Z])
            pin_barrel(total_len);
}

module horn_boss(edge) {
    x = END_MARGIN - SERVO_EXT_LEN;
    y = (edge == "front") ? 0 : BASE_SIZE;
    translate([x, y, HINGE_Z])
        rotate([0, 90, 0])
        difference() {
            cylinder(d = SERVO_BOSS_D, h = SERVO_BOSS_T, $fn = 40);
            for (a = [0, 180])
                rotate([0, 0, a])
                    translate([SERVO_HORN_BOLT_CIRCLE / 2, 0, -0.1])
                        cylinder(d = 2.2, h = SERVO_BOSS_T + 0.2, $fn = 16); // horn screw holes, verify size
        }
}

module flap_assembly(edge) {
    flap_panel(edge);
    flap_pin(edge);
    horn_boss(edge);
}

// ---------------- Full combined piece ----------------
module combined_assembly() {
    base_assembly();
    flap_assembly("front");
    flap_assembly("back");
}

combined_assembly();

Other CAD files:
3d-models/bowl/20_base_v2.scad
3d-models/bowl/21_flap_v2.scad
3d-models/bowl/22_servo_mount_v2.scad
3d-models/bowl/23_assembly_v2.scad
3d-models/bowl/combined_v4.stl
3d-models/bowl/hinge_v2.scad
3d-models/bowl/hinge_v4.scad
3d-models/bowl/params_v2.scad
3d-models/cad/01_main_body.scad
3d-models/cad/02_hopper.scad
3d-models/cad/03_hopper_lid.scad
3d-models/cad/04_auger_tube.scad
3d-models/cad/05_auger_screw.scad
3d-models/cad/06_motor_mount.scad
3d-models/cad/07_electronics_tray.scad
3d-models/cad/08_electronics_cover.scad
3d-models/cad/09_bowl.scad
3d-models/cad/10_bowl_bracket.scad
3d-models/cad/11_camera_mount.scad
3d-models/cad/12_camera_bezel.scad
3d-models/cad/13_gate_flap.scad
3d-models/cad/14_gate_hinge_mount.scad
3d-models/cad/15_antenna_arch.scad
3d-models/cad/16_gate_servo_bracket.scad
3d-models/cad/17_gate_bumper.scad
3d-models/cad/18_feet.scad
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

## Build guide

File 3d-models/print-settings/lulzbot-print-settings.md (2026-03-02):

# Cat Feeder 5000 — LulzBot Print Settings
LulzBot Taz 6 / Pro. Slicer: Cura LulzBot Edition or PrusaSlicer with LulzBot profile.

## Filament Prep
- **PETG**: Dry at 65°C for 4–6 hours before printing. PETG is hygroscopic — wet filament causes stringing and weak layers.
- **TPU**: Dry at 50°C for 2–4 hours. Load slowly; use direct drive (LulzBot Taz is direct drive — good for TPU).

---

## PETG Profile (Structural Parts)

| Setting | Value |
|---|---|
| Nozzle temp | 240°C |
| Bed temp | 75°C (PEI sheet) |
| Nozzle size | 0.5mm |
| Layer height | 0.25mm (standard) / 0.2mm (detail) / 0.15mm (fine/food-contact) |
| First layer height | 0.35mm |
| Print speed | 45 mm/s |
| First layer speed | 20 mm/s |
| Perimeters | 3 (food-contact parts: use 4) |
| Top/bottom layers | 4 |
| Cooling | 30–50% fan (PETG needs some cooling but not too much) |
| Retraction | 1.5mm @ 25mm/s (direct drive) |
| Z-hop | 0.2mm |
| Seam | Rear or aligned |

## TPU Profile (Flexible Parts: bumper, feet)

| Setting | Value |
|---|---|
| Nozzle temp | 220°C |
| Bed temp | 45°C |
| Nozzle size | 0.5mm |
| Layer height | 0.2mm (feet) / 0.3mm (bumper) |
| Print speed | 25 mm/s max |
| Retraction | DISABLED (TPU does not retract well — causes jams) |
| Perimeters | 3 |
| Infill | 15% (feet) / 30% (bumper) |
| Cooling | 50% |
| Combing | ON (avoids travel moves over infill, reduces stringing) |

---

## Per-Part Settings

| # | Part | Material | Layer H | Infill | Supports | Orientation | Notes |
|---|---|---|---|---|---|---|---|
| 01 | Main body | PETG | 0.25mm | 40% | No | Upright (Z+) | Largest print ~6h |
| 02 | Hopper | PETG | 0.25mm | 25% | No | Upright | Funnel thin walls |
| 03 | Hopper lid | PETG | 0.2mm | 20% | No | Upright | Snap lip down |
| 04 | Auger tube | PETG | 0.2mm | 30% | No | Upright | Smooth bore critical |
| 05 | Auger screw | PETG | 0.15mm | 60% | Yes | VERTICAL (thread integrity) | Supports on thread underside |
| 06 | Motor mount | PETG | 0.25mm | 40% | No | Flat | N20 or NEMA14 variant |
| 07 | Electronics tray | PETG | 0.25mm | 30% | No | Flat | Open side up |
| 08 | Electronics cover | PETG | 0.2mm | 20% | No | Flat | Vent slots up |
| 09 | Bowl | PETG | 0.15mm | 30% | No | Upright | 4 perimeters, food-safe |
| 10 | Bowl bracket | PETG | 0.25mm | 40% | No | Flat | |
| 11 | Camera mount | PETG | 0.2mm | 35% | Yes | Upright | Supports under camera head |
| 12 | Camera bezel | PETG | 0.2mm | 20% | No | Flat | |
| 13 | Gate flap | PETG | 0.15mm | 40% | No | Flat (face down) | Smooth cat-facing surface |
| 14 | Gate hinge mount | PETG | 0.2mm | 40% | No | Flat | |
| 15 | Antenna arch | PETG | 0.2mm | 25% | No | UPRIGHT | Thin walls need upright orientation; NO top perimeters over coil channel |
| 16 | Servo bracket | PETG | 0.2mm | 40% | No | Flat | |
| 17 | Gate bumper | TPU | 0.2mm | 30% | No | Flat | TPU profile, slow |
| 18 | Feet ×4 | TPU | 0.3mm | 15% | No | Peg up | Print all 4 at once |

---

## Antenna Arch Special Notes (Part 15)

The coil channel in the arch top bridge must be open on the top surface — no bridging perimeters over it. In Cura/PrusaSlicer:
- Use "Surface mode: Normal" 
- The channel is a blind slot from the top — the slicer will naturally leave it open since it's open geometry
- After printing, seat the wound coil in the channel and fix with food-safe 2-part epoxy
- Route cable through the 5mm channel in the left leg to the electronics bay

## Food-Contact Parts: Post-Processing

Parts 02 (hopper), 04 (auger tube), 05 (auger screw), 09 (bowl):
1. Wash with warm soapy water, rinse well
2. Inspect for layer gaps or rough areas — sand smooth with 400 grit if needed
3. Apply thin coat of food-safe mineral oil or food-grade PTFE lubricant to auger screw/tube interface only
4. Do NOT use acetone or other solvents (degrades PETG surface)

## Heat-Set Insert Installation

All M3 inserts: use soldering iron at 200–220°C. Press insert flush with surface, perpendicular. Allow 60s to cool before stressing.
Insert bore diameter in all parts: **4.7mm** (M3 insert OD = 4.5mm + 0.2mm print tolerance).

## Print Order (Recommended)

Print larger/longer parts first to catch any issues before committing to smaller detail prints:
1. Main body (01) — longest, catches any bed leveling issues
2. Hopper (02) + Auger tube (04) in same session if bed space allows
3. Auger screw (05) — most precision-sensitive, print alone
4. Bowl (09) — food-contact, inspect carefully
5. Gate assembly: flap (13) + hinge mount (14) + servo bracket (16) + bumper (17)
6. Antenna arch (15) — inspect coil channel carefully before continuing
7. Remaining parts in any order

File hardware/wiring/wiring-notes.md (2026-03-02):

# Cat Feeder 5000 — Wiring Reference
**Version**: 1.2

---

## Arduino Nano Pin Map

| Pin | Function | Connected To | Notes |
|-----|---|---|---|
| D2  | Motor STEP | A4988 STEP / L298N PWM | |
| D3  | Motor DIR | A4988 DIR / L298N IN2 | |
| D4  | Motor Enable | A4988 EN / L298N ENA | Active LOW for A4988 |
| D5  | RFID MOD | EM4095 MOD | Modulation input |
| D6  | RFID RF_OFF | EM4095 RF_OFF | Pull HIGH to disable RF field |
| D8  | Gate Servo PWM | SG90 signal wire | Swing-up gate |
| D9  | Status LED | LED + 220Ω resistor → GND  | |
| D10 | RFID CS/SHD | EM4095 SHD | Pull LOW to enable chip |
| D11 | SPI MOSI | EM4095 (if SPI mode) | |
| D12 | DEMOD_OUT | EM4095 DEMOD_OUT | Manchester encoded FDX-B data |
| D13 | SPI SCK | EM4095 (if SPI mode) | |
| A2  | Buzzer | Active buzzer + | Buzzer − to GND |
| A4  | I2C SDA (optional) | Load cell amp SDA | |
| A5  | I2C SCL (optional) | Load cell amp SCL | |
| 5V  | Power out | EM4095 VCC, servo VCC | |
| GND | Ground | All component grounds | Common ground |

---

## EM4095 Connections

| EM4095 Pin | Connects To | Notes |
|---|---|---|
| VDD | Arduino 5V | 5V native — no level shifter needed |
| GND | Arduino GND | |
| COIL1 | LC tank coil end A | Series with tuning cap to COIL2 |
| COIL2 | LC tank coil end B | |
| DEMOD_OUT  | Arduino D12 | Manchester-encoded FDX-B bit stream |
| MOD | Arduino D5 | For write; tie LOW if read-only |
| RF_OFF | Arduino D6 | Pull HIGH to disable field between reads |
| SHD | Arduino D10 (GND)  | Pull LOW to enable; use pin for software control |

---

## LC Tank Antenna (134.2 kHz)

The antenna coil and tuning capacitor form a resonant LC tank at 134.2 kHz.

**Resonance formula**: `f = 1 / (2π × √(L × C))`

**Target**: f = 134,200 Hz

**Procedure**:
1. Wind flat spiral coil: ~12cm diameter, 28 AWG magnet wire, ~15 turns
2. Measure coil inductance (L) with LCR meter or Arduino LC meter sketch
3. Solve for C: `C = 1 / ((2π × f)² × L)`
4. Use closest standard capacitor value; trim with small parallel cap

**Example** (15 turns, ~12cm dia): L ≈ 60–80 µH → C ≈ 17–24 nF at 134.2 kHz

**Coil placement**: Horizontal, in the overhead antenna arch housing,
centered 5–8 cm above where the cat's shoulders sit while eating.

---

## SG90 Servo (Swing-Up Gate)

| Servo wire | Connects to |
|---|---|
| Brown/Black | GND |
| Red | 5V |
| Orange/Yellow | Arduino D8 |

- **Closed angle**: 10° (gate blocks bowl opening)
- **Open angle**: 95° (gate retracts upward into feeder body)
- Adjust angles in firmware `GATE_CLOSED_ANGLE` / `GATE_OPEN_ANGLE` constants

---

## Power Architecture

```
USB-C 5V 3A PSU
├── Raspberry Pi Zero 2 W (via USB-C)
│     └── USB-A → Arduino Nano (5V via USB)
│           ├── EM4095 + antenna coil (5V, ~50–100mA)
│           ├── SG90 servo (5V, ~250mA peak)
│           ├── Motor driver (5V logic; motor on same 5V rail)
│           ├── Buzzer (5V)
│           └── Status LED (5V via 220Ω)
└── (Optional) Separate 5–12V supply for auger motor if high torque needed
```

> **Note**: SG90 peak current (250mA) + motor can exceed USB current limits.
> If brownouts occur, power Pi and Arduino from separate USB ports on the PSU,
> or use a powered USB hub.

---

## Serial Connection (Pi ↔ Arduino)

- Pi USB-A → Arduino Nano USB Mini-B
- Port on Pi: `/dev/ttyUSB0` (or `/dev/ttyACM0` — check `dmesg` after plugging in)
- Baud rate: 115200
- Set `SERIAL_PORT` env variable in software config if different

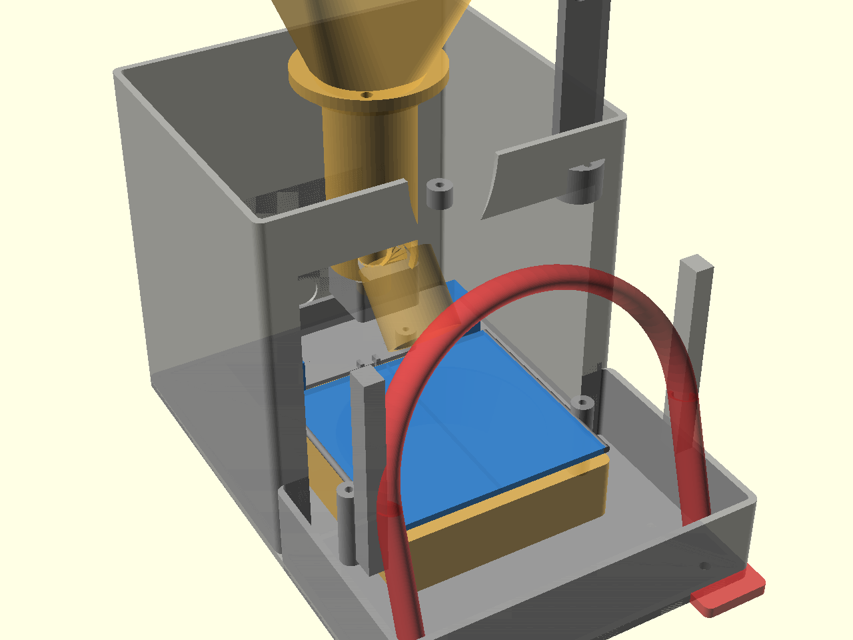
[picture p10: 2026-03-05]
3d-models/renders/assembly_corner.png

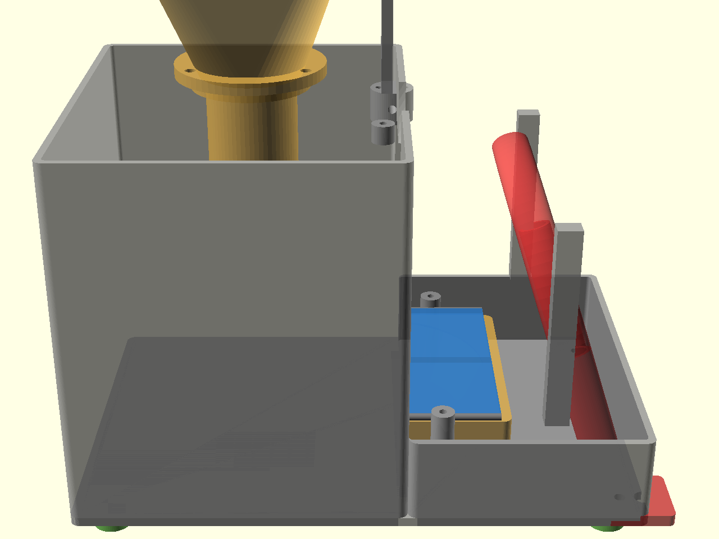
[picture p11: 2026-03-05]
3d-models/renders/assembly_side.png

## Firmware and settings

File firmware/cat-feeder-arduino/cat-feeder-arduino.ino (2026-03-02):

/**
 * Cat Feeder 5000 — Arduino Firmware
 * v1.0 (first iteration)
 *
 * Hardware:
 *   - Arduino Nano
 *   - EM4095 RFID AFE + custom flat coil (134.2 kHz, FDX-B)
 *   - SG90 servo (swing-up gate)
 *   - Motor driver (auger)
 *   - Active buzzer
 *   - Optional: status LED
 *
 * Serial protocol (115200 baud) with Raspberry Pi:
 *   Pi → Arduino:  FEED:<grams>, GATE:OPEN, GATE:CLOSE, BUZZ:<pattern>
 *   Arduino → Pi:  EVENT:RFID:<uid>, STATUS:READY, STATUS:GATE:OPEN,
 *                  STATUS:GATE:CLOSED, STATUS:FEED:DONE, ERROR:<msg>
 */

#include <Servo.h>

// ─── Pin Definitions ─────────────────────────────────────────────────────────
#define PIN_MOTOR_STEP   2    // Auger stepper STEP (or DC motor PWM)
#define PIN_MOTOR_DIR    3    // Auger stepper DIR (or DC motor IN2)
#define PIN_MOTOR_EN     4    // Motor driver enable (active LOW for A4988)
#define PIN_RFID_MOD     5    // EM4095 MOD (modulation)
#define PIN_RFID_RF_OFF  6    // EM4095 RF_OFF (pull HIGH to disable RF field)
#define PIN_GATE_SERVO   8    // SG90 servo PWM
#define PIN_LED          9    // Status LED
#define PIN_RFID_CS      10   // EM4095 CS / SHD (active LOW to enable)
#define PIN_RFID_DEMOD   12   // EM4095 DEMOD_OUT — Manchester encoded FDX-B data
#define PIN_BUZZER       A2   // Active buzzer

// ─── Gate Servo Angles ────────────────────────────────────────────────────────
#define GATE_CLOSED_ANGLE  10   // Servo angle when gate is closed (blocking bowl)
#define GATE_OPEN_ANGLE    95   // Servo angle when gate is open (retracted upward)

// ─── Feeding Constants ────────────────────────────────────────────────────────
#define STEPS_PER_GRAM     45   // Calibrate: stepper steps per gram of food
#define MOTOR_STEP_DELAY   800  // Microseconds between steps (lower = faster)

// ─── Gate Auto-Close ─────────────────────────────────────────────────────────
#define GATE_TIMEOUT_MS    30000  // Auto-close gate after 30 seconds

// ─── FDX-B / EM4095 RFID ─────────────────────────────────────────────────────
// FDX-B (ISO 11784/11785) bit rate = 134200 / 32 = ~4194 bps
// Manchester half-period = ~119 µs
// We sample DEMOD_OUT via Timer2 interrupt at ~2× bit rate (~238 µs period)
#define FDXB_BIT_PERIOD_US  238   // Full bit period in µs
#define FDXB_HALF_PERIOD_US 119   // Half bit period
#define FDXB_FRAME_BITS     128   // Full FDX-B frame length
#define FDXB_HEADER_BITS    11    // 11 leading '1' bits + stop '0'
#define FDXB_POLL_INTERVAL  100   // ms between read attempts

// ─── State ───────────────────────────────────────────────────────────────────
Servo gateServo;
bool  gateOpen         = false;
unsigned long gateOpenTime = 0;

// RFID sampling state (used in pollRFID)
uint8_t  rfidBuf[16];   // 128 bits = 16 bytes
uint8_t  rfidBitCount   = 0;
bool     rfidFrameReady = false;

// Serial command buffer
#define CMD_BUF_SIZE 32
char     cmdBuf[CMD_BUF_SIZE];
uint8_t  cmdLen = 0;

// ─── Setup ───────────────────────────────────────────────────────────────────
void setup() {
  Serial.begin(115200);

  // Gate servo
  gateServo.attach(PIN_GATE_SERVO);
  gateServo.write(GATE_CLOSED_ANGLE);

  // Motor pins
  pinMode(PIN_MOTOR_STEP, OUTPUT);
  pinMode(PIN_MOTOR_DIR,  OUTPUT);
  pinMode(PIN_MOTOR_EN,   OUTPUT);
  digitalWrite(PIN_MOTOR_EN, HIGH);  // Disable motor at startup

  // RFID pins
  pinMode(PIN_RFID_DEMOD,  INPUT);
  pinMode(PIN_RFID_RF_OFF, OUTPUT);
  pinMode(PIN_RFID_MOD,    OUTPUT);
  pinMode(PIN_RFID_CS,     OUTPUT);
  digitalWrite(PIN_RFID_RF_OFF, LOW);   // RF field ON
  digitalWrite(PIN_RFID_CS,    LOW);    // Enable EM4095
  digitalWrite(PIN_RFID_MOD,   LOW);

  // Misc
  pinMode(PIN_LED,     OUTPUT);
  pinMode(PIN_BUZZER,  OUTPUT);
  digitalWrite(PIN_BUZZER, LOW);
  digitalWrite(PIN_LED, HIGH);

  delay(200);
  Serial.println("STATUS:READY");
  blinkLed(3, 100);
}

// ─── Main Loop ────────────────────────────────────────────────────────────────
void loop() {
  readSerial();
  pollRFID();
  checkGateTimeout();
}

// ─── Serial Input ─────────────────────────────────────────────────────────────
void readSerial() {
  while (Serial.available()) {
    char c = Serial.read();
    if (c == '\n' || c == '\r') {
      if (cmdLen > 0) {
        cmdBuf[cmdLen] = '\0';
        handleCommand(cmdBuf);
        cmdLen = 0;
      }
    } else if (cmdLen < CMD_BUF_SIZE - 1) {
      cmdBuf[cmdLen++] = c;
    }
  }
}

void handleCommand(const char* cmd) {
  if (strcmp(cmd, "GATE:OPEN") == 0) {
    openGate();
  } else if (strcmp(cmd, "GATE:CLOSE") == 0) {
    closeGate();
  } else if (strncmp(cmd, "FEED:", 5) == 0) {
    int grams = atoi(cmd + 5);
    if (grams > 0 && grams <= 500) {
      dispenseFood(grams);
    } else {
      Serial.println("ERROR:INVALID_FEED_AMOUNT");
    }
  } else if (strncmp(cmd, "BUZZ:", 5) == 0) {
    int pattern = atoi(cmd + 5);
    buzzerPattern(pattern);
  } else {
    Serial.print("ERROR:UNKNOWN_CMD:");
    Serial.println(cmd);
  }
}

// ─── Gate Control ─────────────────────────────────────────────────────────────
void openGate() {
  gateServo.write(GATE_OPEN_ANGLE);
  gateOpen = true;
  gateOpenTime = millis();
  delay(300);  // Allow servo to reach position
  Serial.println("STATUS:GATE:OPEN");
  digitalWrite(PIN_LED, LOW);   // LED off when gate open = eating
}

void closeGate() {
  gateServo.write(GATE_CLOSED_ANGLE);
  gateOpen = false;
  delay(300);
  Serial.println("STATUS:GATE:CLOSED");
  digitalWrite(PIN_LED, HIGH);
}

void checkGateTimeout() {
  if (gateOpen && (millis() - gateOpenTime >= GATE_TIMEOUT_MS)) {
    closeGate();
  }
}

// ─── Food Dispensing ──────────────────────────────────────────────────────────
void dispenseFood(int grams) {
  long steps = (long)grams * STEPS_PER_GRAM;
  digitalWrite(PIN_MOTOR_DIR, HIGH);
  digitalWrite(PIN_MOTOR_EN,  LOW);   // Enable motor

  for (long i = 0; i < steps; i++) {
    digitalWrite(PIN_MOTOR_STEP, HIGH);
    delayMicroseconds(MOTOR_STEP_DELAY);
    digitalWrite(PIN_MOTOR_STEP, LOW);
    delayMicroseconds(MOTOR_STEP_DELAY);
  }

  digitalWrite(PIN_MOTOR_EN, HIGH);  // Disable motor
  Serial.println("STATUS:FEED:DONE");
  buzzerPattern(1);  // Short confirmation beep
}

// ─── RFID — FDX-B Manchester Decode ──────────────────────────────────────────
//
// EM4095 outputs a demodulated Manchester stream on DEMOD_OUT.
// FDX-B Manchester encoding:
//   '0' = LOW→HIGH transition at bit midpoint
//   '1' = HIGH→LOW transition at bit midpoint
// Full bit period = ~238 µs at 134.2 kHz / 32
//
// Strategy: poll DEMOD_OUT, detect transitions, measure timing,
// accumulate bits into a 128-bit buffer, validate and report UID.

#define DEMOD_SAMPLE_TIMEOUT_US 600   // Max time to wait for a transition
#define FDXB_SYNC_ONES          10    // Need 10 consecutive '1' bits for sync

void pollRFID() {
  static unsigned long lastPoll = 0;
  if (millis() - lastPoll < FDXB_POLL_INTERVAL) return;
  lastPoll = millis();

  uint8_t bits[FDXB_FRAME_BITS];
  int     bitCount = 0;
  int     syncCount = 0;
  bool    synced = false;

  // Sample the bit stream for up to ~50ms (enough for 1–2 frames)
  unsigned long deadline = micros() + 50000UL;

  while (micros() < deadline && bitCount < FDXB_FRAME_BITS) {
    int bit = readManchesterBit();
    if (bit < 0) break;  // Timeout reading bit

    if (!synced) {
      if (bit == 1) {
        syncCount++;
        if (syncCount >= FDXB_SYNC_ONES) synced = true;
      } else {
        // '0' after enough '1' bits = start of data
        if (syncCount >= FDXB_SYNC_ONES) {
          synced = true;
          bitCount = 0;  // Start collecting data bits
        } else {
          syncCount = 0;
        }
      }
    } else {
      bits[bitCount++] = (uint8_t)bit;
    }
  }

  if (bitCount >= 64) {
    // Attempt to extract UID from the frame
    char uid[24];
    if (parseFDXBFrame(bits, bitCount, uid)) {
      Serial.print("EVENT:RFID:");
      Serial.println(uid);
      buzzerPattern(1);
      blinkLed(2, 80);
    }
  }
}

// Read one Manchester-encoded bit from DEMOD_OUT.
// Returns 0 or 1, or -1 on timeout.
int readManchesterBit() {
  // Wait for line to settle, then sample at mid-bit
  // We measure the pulse width to determine bit value.

  unsigned long t0;
  int startLevel = digitalRead(PIN_RFID_DEMOD);

  // Wait for transition (start of bit period)
  t0 = micros();
  while (digitalRead(PIN_RFID_DEMOD) == startLevel) {
    if (micros() - t0 > DEMOD_SAMPLE_TIMEOUT_US) return -1;
  }

  // We are now at a transition — wait half a bit period to sample mid-bit
  delayMicroseconds(FDXB_HALF_PERIOD_US / 2);
  int midSample = digitalRead(PIN_RFID_DEMOD);

  // Skip rest of bit period
  delayMicroseconds(FDXB_HALF_PERIOD_US / 2);

  // In Manchester: LOW→HIGH = '0', HIGH→LOW = '1'
  // midSample after a rising edge is HIGH → was LOW before = '0'
  // midSample after a falling edge is LOW → was HIGH before = '1'
  return (startLevel == LOW) ? 0 : 1;
}

// Parse a FDX-B bit stream and extract the 64-bit UID as hex string.
// FDX-B frame (after header): 38-bit national ID + 10-bit country code
// + status bits + CRC. We extract national+country as the UID.
bool parseFDXBFrame(uint8_t* bits, int count, char* uidOut) {
  if (count < 64) return false;

  // Extract 38-bit national ID (bits 0–37)
  unsigned long long nationalID = 0;
  for (int i = 0; i < 38; i++) {
    nationalID = (nationalID << 1) | bits[i];
  }

  // Extract 10-bit country code (bits 38–47)
  uint16_t countryCode = 0;
  for (int i = 38; i < 48; i++) {
    countryCode = (countryCode << 1) | bits[i];
  }

  // Format as "CCC-NNNNNNNNNNNN" (country-national in decimal)
  // Or as hex for simplicity in first iteration
  unsigned long high = (unsigned long)(nationalID >> 16);
  unsigned long low  = (unsigned long)(nationalID & 0xFFFF);
  snprintf(uidOut, 24, "%03u-%05lu%04lu", countryCode, high, low);

  return (nationalID > 0 || countryCode > 0);
}

// ─── Buzzer Patterns ──────────────────────────────────────────────────────────
// Pattern 1 = short beep (access granted)
// Pattern 2 = two beeps (feeding complete)
// Pattern 3 = long error tone
void buzzerPattern(int pattern) {
  switch (pattern) {
    case 1:
      tone(PIN_BUZZER, 2000, 80);
      break;
    case 2:
      tone(PIN_BUZZER, 2000, 80);
      delay(150);
      tone(PIN_BUZZER, 2000, 80);
      break;
    case 3:
      tone(PIN_BUZZER, 800, 400);
      break;
    default:
      break;
  }
}

// ─── LED Helper ───────────────────────────────────────────────────────────────
void blinkLed(int times, int ms) {
  for (int i = 0; i < times; i++) {
    digitalWrite(PIN_LED, LOW);
    delay(ms);
    digitalWrite(PIN_LED, HIGH);
    delay(ms);
  }
}

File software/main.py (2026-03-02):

"""
Cat Feeder 5000 — Main Daemon
Entry point. Wires together all subsystems and runs forever.

Usage:
    python main.py

Environment variables (see config.py):
    FEEDER_ID, SERIAL_PORT, DB_PATH, CAMERA_ENABLED, API_PORT
"""
import logging
import signal
import sys
import threading

import db
from config import FEEDER_ID, API_HOST, API_PORT
from serial_bridge import SerialBridge
from rfid.gate_controller import GateController
from rfid.rfid_access import RFIDAccessController
from scheduler import FeedingScheduler
from camera.camera import CameraModule

logging.basicConfig(
    level=logging.INFO,
    format="%(asctime)s [%(levelname)s] %(name)s: %(message)s",
    handlers=[
        logging.StreamHandler(sys.stdout),
        logging.FileHandler("/var/log/catfeeder.log"),
    ]
)
log = logging.getLogger(__name__)


def main():
    log.info("Cat Feeder 5000 starting — Feeder ID %d", FEEDER_ID)

    # ── Database ──────────────────────────────────────────────────────────────
    db.init_db()

    # ── Serial bridge ─────────────────────────────────────────────────────────
    serial = SerialBridge()
    serial.connect()

    # ── Gate controller ───────────────────────────────────────────────────────
    gate = GateController(serial)

    # ── RFID access controller ────────────────────────────────────────────────
    rfid = RFIDAccessController(serial, gate)

    # ── Feeding scheduler ─────────────────────────────────────────────────────
    scheduler = FeedingScheduler(serial)
    scheduler.start()

    # ── Camera ────────────────────────────────────────────────────────────────
    camera = CameraModule()
    camera.start()

    # ── Flask API ─────────────────────────────────────────────────────────────
    from api.app import create_app
    app = create_app(serial=serial, gate=gate, scheduler=scheduler, camera=camera)
    api_thread = threading.Thread(
        target=lambda: app.run(host=API_HOST, port=API_PORT, debug=False),
        daemon=True
    )
    api_thread.start()
    log.info("API server running on %s:%d", API_HOST, API_PORT)

    # ── Graceful shutdown ─────────────────────────────────────────────────────
    def shutdown(sig, frame):
        log.info("Shutdown signal received")
        scheduler.stop()
        camera.stop()
        gate.close(reason="shutdown")
        serial.disconnect()
        sys.exit(0)

    signal.signal(signal.SIGINT,  shutdown)
    signal.signal(signal.SIGTERM, shutdown)

    log.info("Cat Feeder 5000 running. Press Ctrl+C to stop.")
    signal.pause()


if __name__ == "__main__":
    main()

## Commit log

2026-03-02 RFID redesign: implanted chip, EM4095, swing-up gate
    - Replace MFRC522 (13.56 MHz) with EM4095 LF AFE tuned to 134.2 kHz
    to read cats' implanted FDX-B microchips (no collar required)
    - Add overhead antenna arch: flat coil above shoulder zone for optimal
    chip coupling geometry as cat positions to eat
    - Add LC tank design notes and coil sizing targets
    - Redesign gate from front-pivot to swing-up (hinged at top, retracts
    into feeder body — cannot contact cat's head or back)
    - Update BOM, pin map, wiring, 3D parts, rationale, and risk table
    - Add Phase 1 coil winding and range-test tasks
2026-03-02 First iteration: firmware, software, and hardware docs
    Arduino firmware:
    - EM4095 + FDX-B Manchester decoder for implanted microchips
    - Swing-up gate servo control (open/close/timeout)
    - Auger motor dispensing (steps-per-gram calibration)
    - Serial protocol handler (FEED/GATE/BUZZ commands)
    - Buzzer patterns + status LED
    Python software (Raspberry Pi):
    - config.py: environment-driven config
    - db.py: SQLite schema + CRUD helpers (cats, tags, logs, schedules)
    - serial_bridge.py: threaded serial comms with callback dispatch
    - rfid/rfid_access.py: RFID event handler, access decisions, debounce
    - rfid/gate_controller.py: swing-up gate state machine, auto-close timer
    - scheduler.py: schedule-based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
    [bom.csv]
2026-03-02 Add all 18 OpenSCAD part files, assembly preview, and print docs
    3d-models/cad/:
    - params.scad: shared dimensions, tolerances, colors, utility modules
    (UNIT_W=160 UNIT_D=240 UNIT_H=160, tuned by Lord Chris)
    - 01_main_body.scad: structural shell, front opening, electronics bay,
    auger hole, interior bosses, foot pockets
    - 02_hopper.scad: funnel reservoir ~500mL, hull geometry, mount flange
    - 03_hopper_lid.scad: snap-on lid, fill port, vent slots
    - 04_auger_tube.scad: food channel, smooth bore, exit port, top flange
    - 05_auger_screw.scad: helical auger, motor coupler, set screw
    - 06_motor_mount.scad: N20 or NEMA14 stepper variant
    - 07_electronics_tray.scad: Pi + Arduino pockets, wire channe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
    [01_main_body.scad, 02_hopper.scad, 03_hopper_lid.scad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]
2026-03-03 Fix feeder geometry: front approach opening and halo antenna arch
    Redesigned main body with ground-level approach opening (130×130mm)
    and bowl shelf so the cat can actually reach the food. Converted
    antenna arch from a top-mounted box to a front-mounted halo doorway
    with legs straddling the opening and an overhead bridge housing the
    RFID coil. Fixed assembly_preview positions to match new spatial
    layout. Added missing auger/bowl params back to params.scad.
    [01_main_body.scad, 15_antenna_arch.scad, assembly_preview.scad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]
2026-03-03 Round halo antenna + gate moved behind reading zone
    Redesigned antenna arch as a semicircular ring (round halo) instead
    of rectangular bridge-and-legs. The coil channel follows the circular
    arch — ideal field geometry for reading implanted pet chips. Moved
    the gate from Y=WALL to Y=40mm inside the body so it no longer
    conflicts with the halo at the front face. Updated assembly_preview
    and params to match.
    [01_main_body.scad, 15_antenna_arch.scad, assembly_preview.scad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]
2026-03-05 another iteration
    [01_main_body.scad, 06_motor_mount.scad, 15_antenna_arch.scad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]
2026-03-05 updates to assmebly
    [01_main_body.scad, 02_hopper.scad, 04_auger_tube.scad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]
2026-07-09 bowl design trial
    [combined_v4.3mf, combined_v4.stl, flap.stl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]
2026-07-09 bowl updates
    [10_combined_v4.scad, 20_base_v2.scad, 21_flap_v2.scad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]
2026-07-28 cat-id: add v2 dataset from real Frigate captures + 3-class pipeline
    The v1 model is an 11-image wiring test trained on photos-of-a-screen.
    Replace it with 326 crops pulled from 30 days of real Frigate cat events
    (47 distinct visits), cut from each event's stored bounding box with 8%
    padding out of Frigate's clean snapshots.
    Adds a third class, not_cat. Frigate's COCO detector reliably boxes a dark
    object near the window as a cat at 67-95% confidence; with only two classes
    the classifier is forced to call it Tom or Casper, which is what produces
    the false announcements. not_cat lets it reject those instead.
    Pipeline:
    make_labeler.py builds an offline label.html (1/2/3 keys), darkest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
2026-07-29 cat-id: add label review mode, fix re-label correctness
    make_labeler.py --review seeds the page from labels.json and groups by
    current label, so a crop in the wrong class stands out against its
    neighbours instead of being buried in date order.
    apply_labels.py now rebuilds the class dirs each run. It only ever copied
    before, so a corrected crop kept a stale copy in its old folder and the
    wrong label survived the correction.
    train_v2.py: ImageFolder picked up unlabeled/ as a class and died on it,
    and the random visit split could land zero cat_b crops in val - with only
    38 Caspers across 12 visits that made val accuracy meaningless for him.
    Restrict the dataset to the three real classes and r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
2026-07-29 cat-id: drop near-duplicate crops from the training set
    Frigate re-acquires a stationary cat about once a second, so one 82-minute
    sit on 07-26 produced 55 near-identical frames - a fifth of the cat_a
    class, all the same pose. dedupe.py groups by perceptual hash, keeps the
    sharpest frame per group and moves the rest to data_v2/_dupes/ (outside
    the class dirs train_v2.py reads, so nothing is deleted).
    cat_a 270 -> 180
    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
